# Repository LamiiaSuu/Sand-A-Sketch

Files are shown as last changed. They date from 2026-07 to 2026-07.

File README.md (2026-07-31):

# Sand A Sketch

Sand A Sketch - Hero Shot

The **Sand A Sketch** is a group project created for the university course Prototyping Interactive Objects (Summer 2026) at Hochschule RheinMain – University of Applied Sciences and Arts, Wiesbaden.

It is an **interactive drawing device** inspired by both the classic **Etch A Sketch** toy and **Kinetic Sand tables**. Instead of using a stylus or display, you can use a joystick to guide a small magnetic ball is moved on a plate filled with fine sand. As the magnet moves, it drags the ball through the sand, creating temporary drawings.

The movement is generated by a custom-built, mostly 3d-printed, [CoreXY mechanism](https://corexy.com/). It is powered by two stepper motors controlled by an Arduino. The joystick allows intuitive two-dimensional control while a potentiometer adjusts the drawing speed.

If you want to build your own Sand A Sketch you can! Just follow the instructions below.

Below you will find the:

- [materials](#materials-bom)
- [equipement](#equipment),
- [.stl-Files](#fabrication-files), 
- [code](#code)
- [Step-by-Step instructions](#step-by-step-instructions)

you need to build your own Sand A Sketch.

### Demo Videos

Drawing a...
- [bag](https://github.com/LamiiaSuu/Sand-A-Sketch/blob/6cb06aaf5f8eaca17e64170e79de1ecc5a618b9c/Footage/Showcase%20Videos/Bag.mp4)
- [heart](https://github.com/LamiiaSuu/Sand-A-Sketch/blob/6cb06aaf5f8eaca17e64170e79de1ecc5a618b9c/Footage/Showcase%20Videos/Heart.mp4)
- [house](https://github.com/LamiiaSuu/Sand-A-Sketch/blob/6cb06aaf5f8eaca17e64170e79de1ecc5a618b9c/Footage/Showcase%20Videos/House.mp4)

## MATERIALS (BOM)
- 1x [Arduino Nano](https://store.arduino.cc/products/arduino-nano)
- 1x Arduino Nano Power Cable
- 1x Breadboard
- Jumper Cables
- 2x 28BYJ-48 – 5V Stepper Motors
- 1x Joystick
- 1x Potentiometer
- 1x Cube Neodymium Magnet - 8 x 8 x 8 mm 
- 1x Magnetic ball - 8 mm
- 1x [6mm timing belt & pieces](https://amzn.eu/d/0blO36EH)
- 2x metal rods - 3 mm x 150 mm
- 2x metal rods - 3 mm x 200 mm
- fine mechanics oil

## EQUIPMENT

**Equipment**
- 3d printer

**Tools**
- cutter knife
- cutting mat
- scissors
- superglue

**Materials**
- Acrylic glass/Plexiglass
- Thick cardboard
- Fine sand/Quartz sand
- PLA filament

**Software**
- [Arduino IDE](https://docs.arduino.cc/software/ide/)
- [CheapStepper Library (v.0.2.1) by Tyler Henry](https://docs.arduino.cc/libraries/cheapstepper/)

## FABRICATION FILES

### Base Enclosure & Sand-Top
- 1x [SandTop.stl](stl/Base%20Enclosure%20%26%20SandTop/SandTop.stl) 
- 1x [Base Plate.stl](stl/Base%20Enclosure%20%26%20SandTop/Base%20Plate.stl) 
- 2x [Enclosure Corner Holder (Motor).stl](stl/Base%20Enclosure%20%26%20SandTop/Enclosure%20Corner%20Holder%20(Motor).stl) 
- 2x [Enclosure Corner Holder (No Motor).stl](stl/Base%20Enclosure%20%26%20SandTop/Enclosure%20Corner%20Holder%20(No%20Motor).stl) 
- *(Optional)* 5× [Cable Channel.stl](stl/Base%20Enclosure%20%26%20SandTop/Cable%20Channel.stl) 

### Controls 
- 1x [Controller Holder Clip.stl](stl/Controls/Controller%20Holder%20Clip.stl) 
- 1x [Upper Controller Part.stl](stl/Controls/Upper%20Controller%20Part.stl) 
- 1x [Lower Controller Part (Base).stl](stl/Controls/Lower%20Controller%20Part%20(Base).stl) 

### CoreXY 
- 1x [SandASketch_Magnet_Holder_Bottom.stl](stl/CoreXY/Individual/SandASketch_Magnet_Holder_Bottom.stl) 
- 1x [SandASketch_Magnet_Holder_Top.stl](stl/CoreXY/Individual/SandASketch_Magnet_Holder_Top.stl) 
- 2x [SandASketch_Motor_Corner.stl](stl/CoreXY/Individual/SandASketch_Motor_Corner.stl) 
- 2x [SandASketch_No_Motor_Corner.stl](stl/CoreXY/Individual/SandASketch_No_Motor_Corner.stl) 
- 2x [SandASketch_No_Motor_Corner_Bar.stl](stl/CoreXY/Individual/SandASketch_No_Motor_Corner_Bar.stl) 
- 2x [SandASketch_Side_Bar_150mm.stl](stl/CoreXY/Individual/SandASketch_Side_Bar_150mm.stl) 
- 2x [SandASketch_Side_Bar_159mm.stl](stl/CoreXY/Individual/SandASketch_Side_Bar_159mm.stl) 
- 2x [SandASketch_Side_Slider.stl](stl/CoreXY/Individual/SandASketch_Side_Slider.stl)
- 2x [SandASketch_Spool.stl](stl/CoreXY/Individual/SandASketch_Spool.stl)
- 4x [SandASketch_Spacer.stl](stl/CoreXY/Individual/SandASketch_Spacer.stl)

## CODE

You can download the code here:
[Sand A Sketch Code](https://github.com/LamiiaSuu/Sand-A-Sketch/blob/7b3ca9e36b72d740b66ece84b7ee0ffa8d913c48/Code/SandASketch.ino)

## STEP BY STEP INSTRUCTIONS

### Step 1: 3D Printing

1. Download all STL files from the [Fabriction Files](#fabrication-files) section 
2. Print all parts in the indicated quantities

**Recommended printer settings:**
- material: PLA
- layer height: 0.2 mm
- infill: 
	- 100% for [SandASketch_No_Motor_Corner_Bar.stl](stl/CoreXY/Individual/SandASketch_No_Motor_Corner_Bar.stl) 
	- 15% for all other parts

**Supports:** 
- **Required:** 
	- SandASketch_Spool.stl
	- SandASketch_Spacer.stl
- **All other parts** were printed successfully without supports on our printer. Depending on your printer and print settings, you may still want to enable supports for overhangs if necessary.

### Step 2: Assembling the CoreXY System

#### 2.1 Assembling the no-motor corners

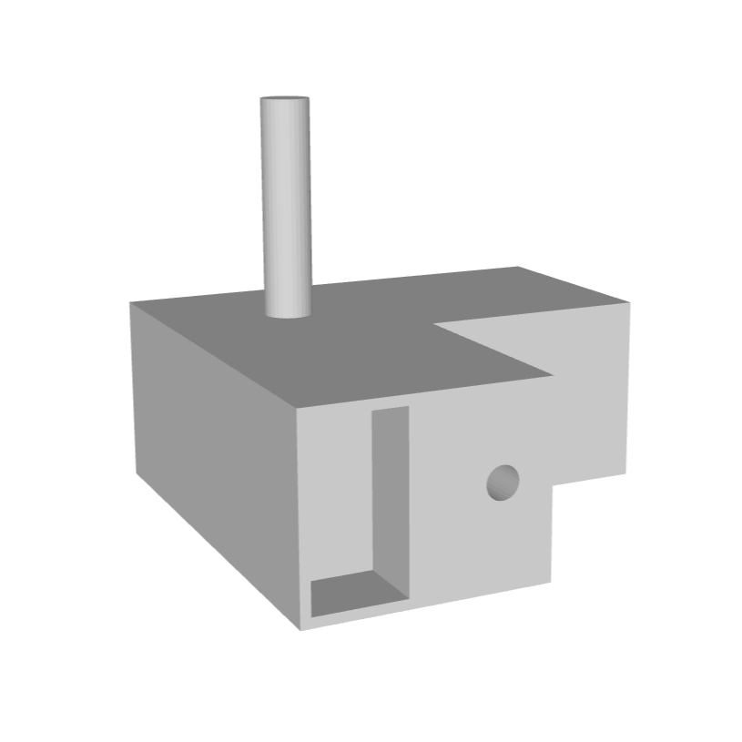
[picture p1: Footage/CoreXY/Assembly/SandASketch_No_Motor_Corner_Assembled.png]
Fully assembled No-Motor Corner

Fully assembled No-Motor Corner

You will need:
- 2x [SandASketch_No_Motor_Corner.stl](stl/CoreXY/Individual/SandASketch_No_Motor_Corner.stl) 
- 2x [SandASketch_No_Motor_Corner_Bar.stl](stl/CoreXY/Individual/SandASketch_No_Motor_Corner_Bar.stl) 
- superglue

1. Put a drop of **superglue** into the holes of the **No-Motor Corner** and insert the **bars** as deep as possible.
2. Wipe any excess glue and set aside to dry for a moment.

------

[Sand-A-Sketch - CoreXY Assembly Video](https://github.com/LamiiaSuu/Sand-A-Sketch/blob/593e7d0ba17ddbd5ef25c9bec1d4cd940d22d459/Footage/Assembly%20Videos/CoreXY%20Assembly.mp4)  
This video demonstrates the complete CoreXY assembly process. The written instructions below correspond to the same assembly.

-----

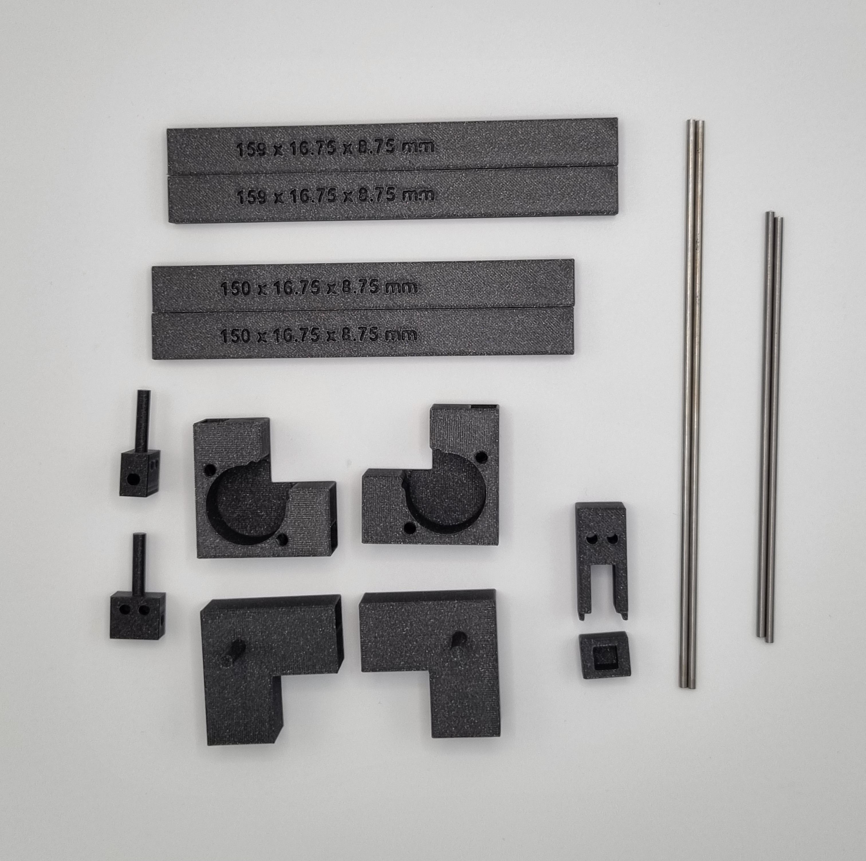
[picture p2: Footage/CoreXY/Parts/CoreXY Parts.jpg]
CoreXY Parts

CoreXY Parts

#### 2.2 Assemble both CoreXY sides
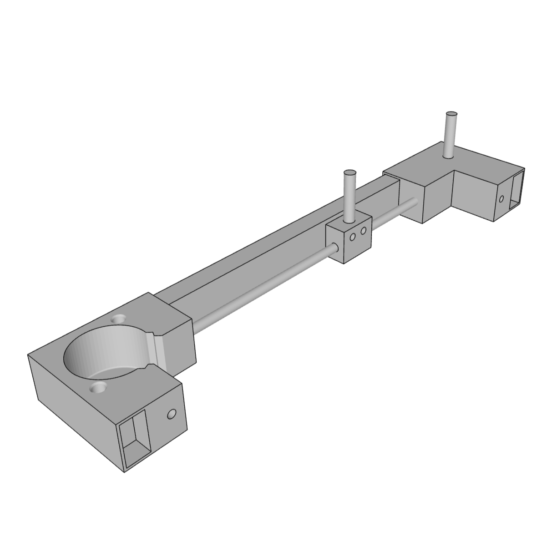
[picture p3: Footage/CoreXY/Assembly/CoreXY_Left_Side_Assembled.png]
Left CoreXY side assembled
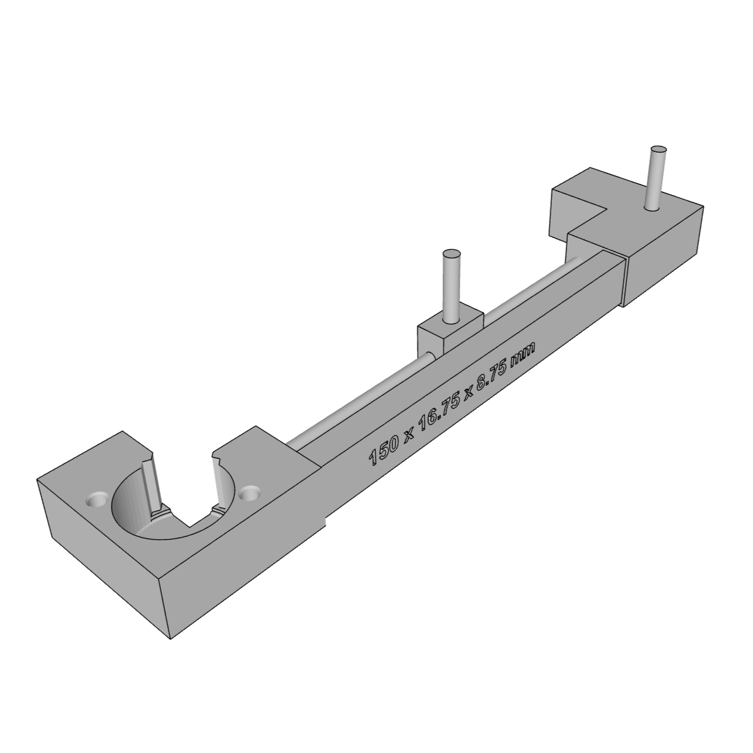
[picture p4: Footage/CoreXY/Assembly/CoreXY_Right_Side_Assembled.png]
Right CoreXY side assembled
|  |  |
|--|--|
| Left CoreXY side | Right CoreXY side |

You will need **for each side**:
- 1x [SandASketch_Motor_Corner.stl](stl/CoreXY/Individual/SandASketch_Motor_Corner.stl) 
- 1x [SandASketch_Side_Bar_150mm.stl](stl/CoreXY/Individual/SandASketch_Side_Bar_150mm.stl) 
- 1x [SandASketch_Side_Slider.stl](stl/CoreXY/Individual/SandASketch_Side_Slider.stl)
- 1x assembled No_Motor_Corner + Bar
- 1x metal rod - 3 mm x 150 mm

First, assemble the **left CoreXY side** by referencing the **left image** above.

1. Orient the **Motor Corner** as shown.
2. Insert the **Side Bar** and **metal rod** into the upper arm of the corner.
3. Slide the **Side Slider** onto the metal rod. Make sure the holes on the side point towards the middle, away from the bar.
4. Orient the **No-Motor Corner** as shown.
5. Insert the free ends of the **Side Bar** and the **metal rod** into the **No-Motor Corner**.

Now **repeat** these steps to assemble the **right CoreXY side** by referencing the **right image.**

#### 2.3 Connect both CoreXY sides
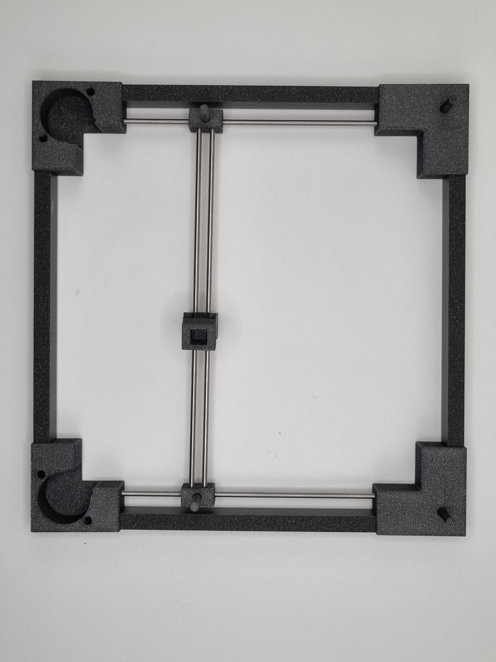
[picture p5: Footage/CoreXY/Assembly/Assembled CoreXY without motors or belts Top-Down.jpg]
Assembled CoreXY - top down
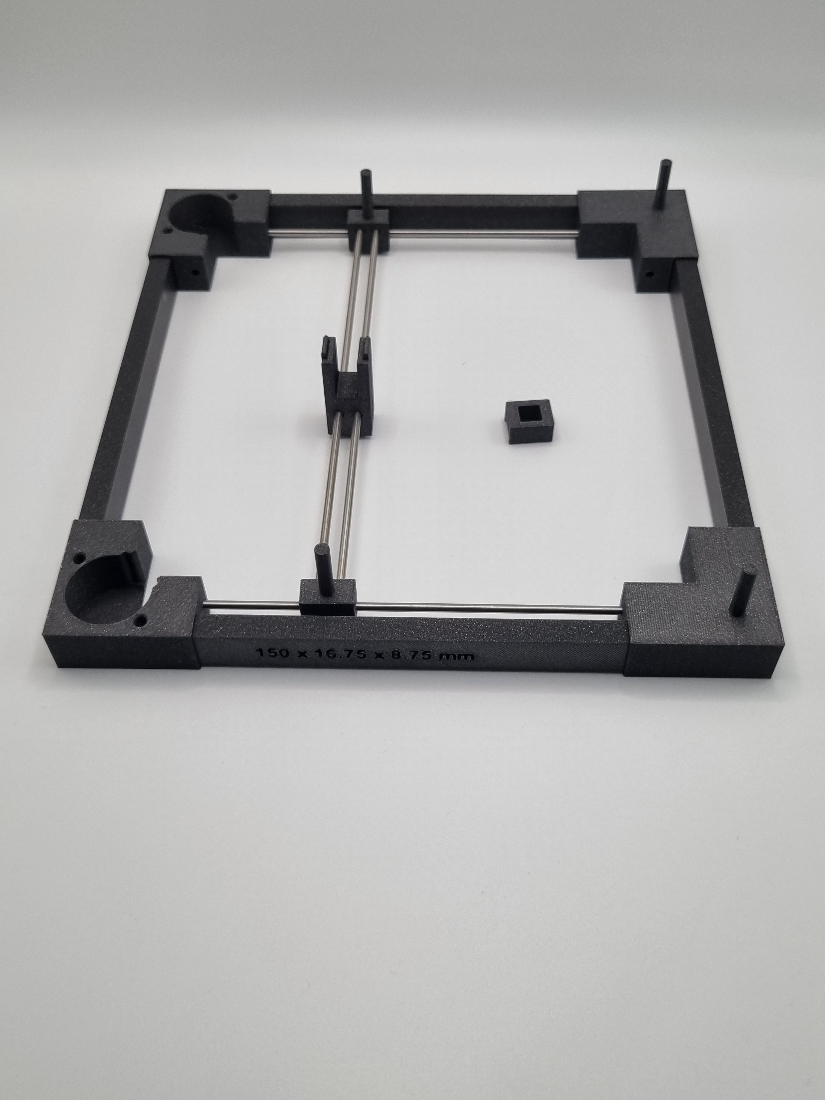
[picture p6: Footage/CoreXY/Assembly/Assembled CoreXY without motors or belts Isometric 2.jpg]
Assembled CoreXY - Isometric
|  |  |
|--|--|
| Assembled CoreXY - top down | Assembled CoreXY - Isometric |

You will need:
- 1x fully assembled left CoreXY side
- 1x fully assembled right CoreXY side
- 2x [SandASketch_Side_Bar_159mm.stl](stl/CoreXY/Individual/SandASketch_Side_Bar_159mm.stl) 
- 1x [SandASketch_Magnet_Holder_Bottom.stl](stl/CoreXY/Individual/SandASketch_Magnet_Holder_Bottom.stl) 
- 2x metal rods - 3 mm x 200 mm

1. Take the **left CoreXY side**.
2. Insert the **Side Bars** into the holes of its **Motor Corner** and **No-Motor Corner**.
3. Insert both **metal rods** into the holes of the **Side Slider**.
4. Slide the **Magnet Holder Bottom** onto both metal rods.
5. Take the **right CoreXY side** and insert the free ends of the **Side Bars** and **metal rods** into it. 

**Tip**
Step 5 can be a bit tricky to do alone. If possible, ask a second person to help you.

**Important** 
Do **not** attach the **Magnet Holder Top** onto the Magnet Holder bottom yet.

Your CoreXY should now look as above. 

#### 2.4 Inserting the Motors

You will need:
- 1x assembled CoreXY
- 2x 28BYJ-48 – 5V Stepper Motors

1. Insert a stepper motor into each **Motor Corner**.
2. Press each motor firmly into place until it is fully seated.

**Note**
The fit is intentionally tight to keep the motors in place.

#### 2.5 Placing the Timing Belt Pulleys

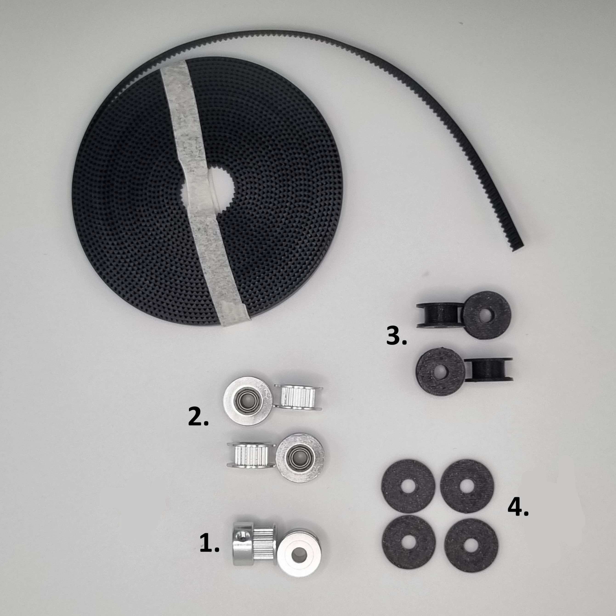
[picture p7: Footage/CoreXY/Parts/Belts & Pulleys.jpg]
Timing Belt, Spools and Spacers

Timing Belt and components.
Parts are labelled **1–4** and referenced in the steps below.

You will need:
- 1x assembled CoreXY with motors inserted
- 2x [SandASketch_Spool.stl](stl/CoreXY/Individual/SandASketch_Spool.stl)
- 4x [SandASketch_Spacer.stl](stl/CoreXY/Individual/SandASketch_Spacer.stl)
- 1x [6mm timing belt & pieces](https://amzn.eu/d/0blO36EH)

1. Take the two pulleys labelled **1** in the image above. Press one onto each stepper motor shaft and tighten the set screws. Your assembly should now look like the image below.
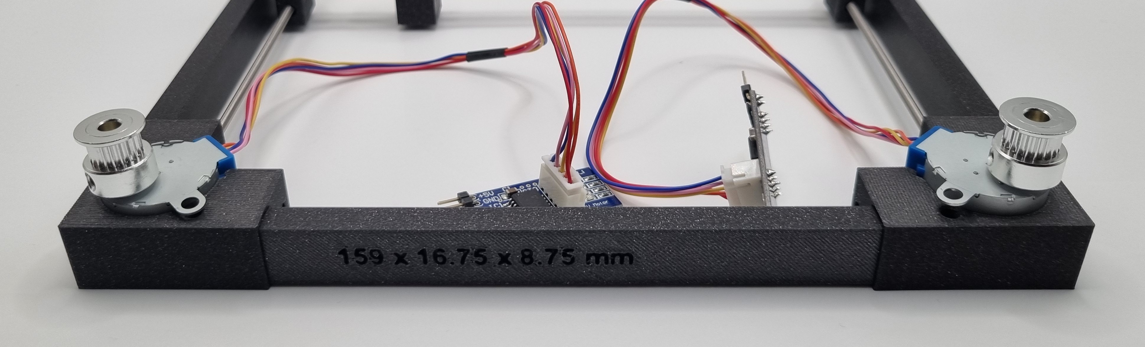
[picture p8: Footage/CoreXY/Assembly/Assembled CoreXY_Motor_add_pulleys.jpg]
Motors with pulleys added

2. Take the two pulleys labelled **2** and place one onto each **No-Motor Corner**.
3. Place one **Spacer** (labelled **3**) on top of each pulley, then place the remaining two pulleys labelled **2** on top.
4. Place one printed **Spool** (labelled **4**) onto each **Side Slider**.
5. Place one **Spacer** on top of each printed spool, then place the remaining two printed spools on top.

Your CoreXY should now look like this:
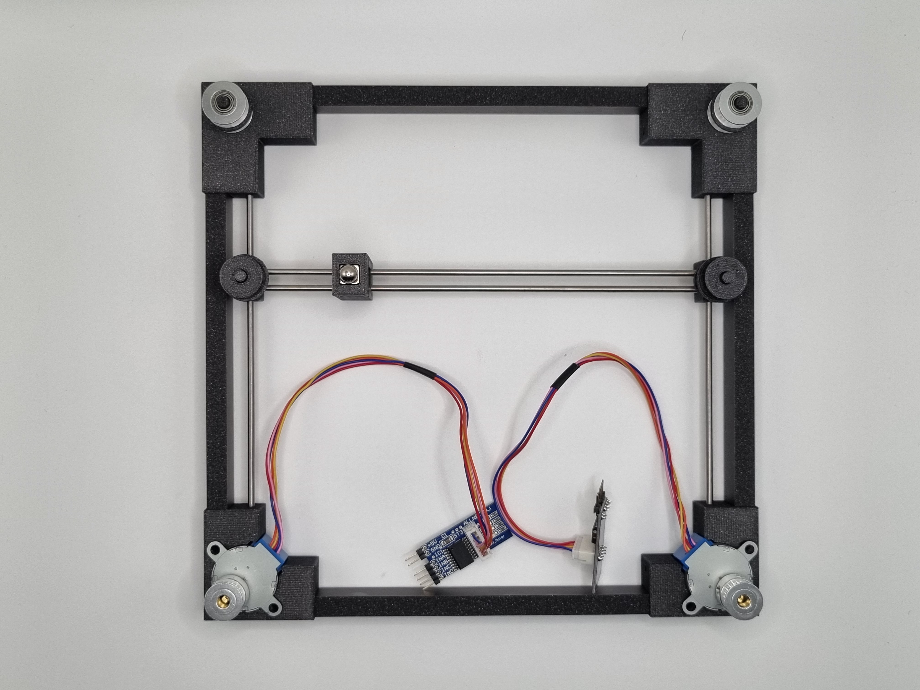
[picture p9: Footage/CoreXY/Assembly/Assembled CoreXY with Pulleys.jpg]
CoreXY with Pulleys
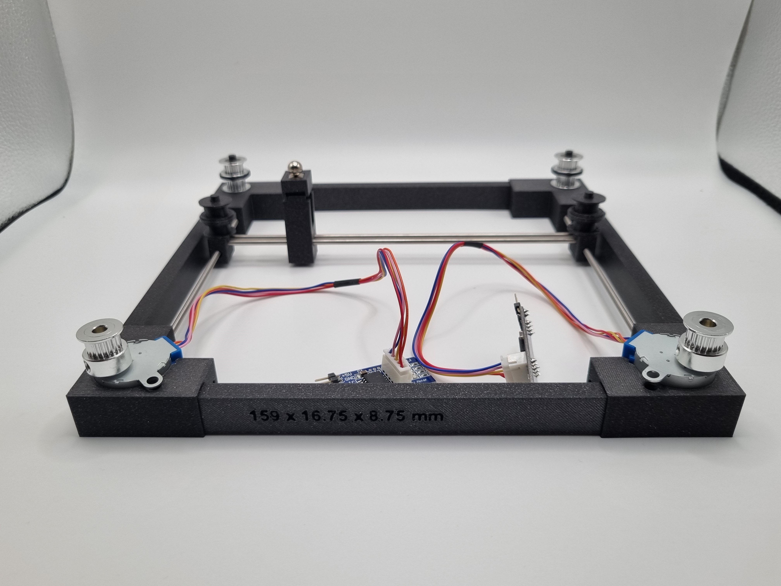
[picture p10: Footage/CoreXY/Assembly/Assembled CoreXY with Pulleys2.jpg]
CoreXY with Pulleys 2
|  |  |
|--|--|
CoreXY with pulleys *(magnet shown for illustration only)*

#### 2.6 Installing the Timing Belt

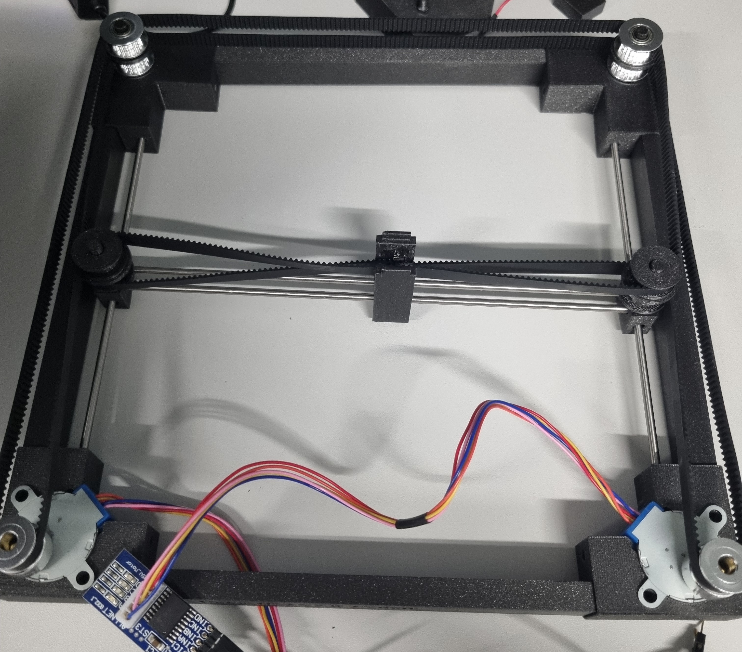
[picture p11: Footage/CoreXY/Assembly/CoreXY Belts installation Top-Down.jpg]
Installed Timing Belt

Installed Timing Belt

You will need:
- 1x assembled CoreXY with motors & pulleys
- 1x [6mm timing belt & pieces](https://amzn.eu/d/0blO36EH)
- scissors
- superglue

Refernce:  
[Manual CoreXY Mechanism by DrRonny on Thingiverse](https://www.thingiverse.com/thing:4167459)  

1. Place the CoreXY in front of you with the Motor Corners closest to you.

**Belt 1:**

2. Take the end of the **Timing Belt** and carefully glue it towards the top of the inside closest to you of the **Magnet Holder Bottom**. The teeth of the belt should be showing away from you/the motors.
3. Route the belt around the pulleys exactly as shown in the refernce. 
4. Cut the belt with 2-3 cm of ease.

**Belt 2:**

5. Take the end **Timing Belt** and carefully glue it towards the bottom of the inside furthest away from you of the **Magnet Holder Bottom**. The teeth of the belt should be in the same direction as **Belt 1**.
6. Route the belt around the pulleys exactly as shown in the refernce. 
7. Cut the belt with 2-3 cm of ease.

**Tensioning:**

8. Pull one belts taut, but not too tight. The Side Slider should **not** be pulled towards the inside of the CoreXY.
9. Use superglue to glue it right beside its other end.
10. Repeat for the other belt .
11. Wait for the glue to fully dry.

#### 2.7 Checking tension

- 1x assembled CoreXY with motors, pulleys & timing belt
- fine mechanics oil
- scissors

1. Aplly some fine mechanics oil to all metal rods
2. Test if the **Side Sliders** move smoothly and the two **metal rods** holding the  **Magnet Holder Bottom** are straight. 
3. Test if the **Magnet Holder Bottom** slides smoothly.
4. Cut the excess Timing Belt off.

**Important**
If the metal rods are not straight the CoreXY will **not** work correctly.
In this case you will likely need to **adjust the tension of the Timing Belt** again.

#### 2.8 Adding the magnet

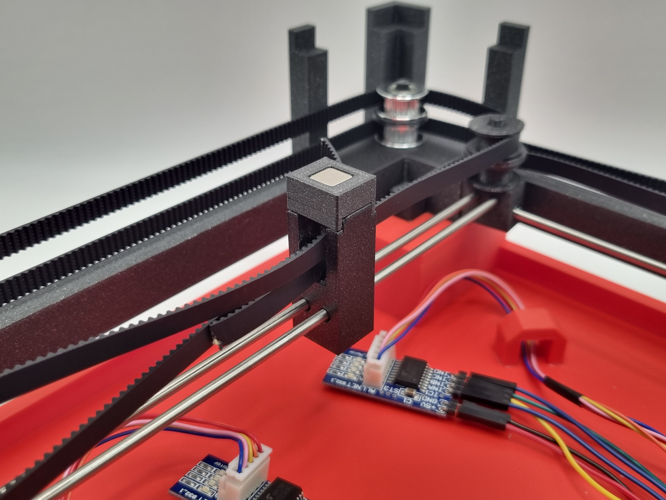
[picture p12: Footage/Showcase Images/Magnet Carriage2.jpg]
Magnet Holder


You will need:
- 1x assembled CoreXY
- 1x [SandASketch_Magnet_Holder_Top.stl](stl/CoreXY/Individual/SandASketch_Magnet_Holder_Top.stl) 
- 1x Cube Neodymium Magnet - 8 x 8 x 8 mm 

1. Place the **magnet** into the **Magnet Holder Top**.
2. Press the **Magnet Holder Top** onto the **Magnet Holder Bottom** until it fits snug.

You have finished assembling the CoreXY!

### Step 3: Assembling the Base Enclosure

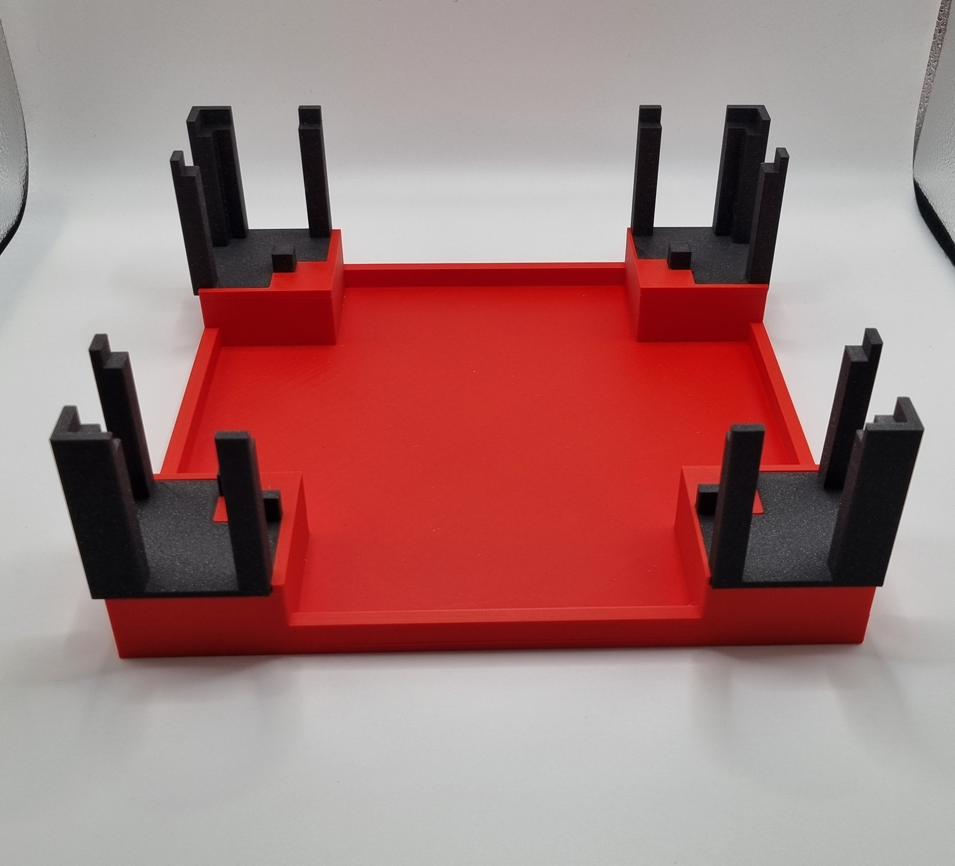
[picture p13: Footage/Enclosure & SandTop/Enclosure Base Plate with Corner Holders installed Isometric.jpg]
Base Enclosure with Corner Holders

Base Enclosure with Corner Holders

You will need:
- 1x assembled CoreXY
- 1x [Base Plate.stl](stl/Base%20Enclosure%20%26%20SandTop/Base%20Plate.stl) 
- 2x [Enclosure Corner Holder (Motor).stl](stl/Base%20Enclosure%20%26%20SandTop/Enclosure%20Corner%20Holder%20(Motor).stl) 
- 2x [Enclosure Corner Holder (No Motor).stl](stl/Base%20Enclosure%20%26%20SandTop/Enclosure%20Corner%20Holder%20(No%20Motor).stl) 
- superglue

1. Take the **Motor Corner Holders** and click them onto the fitting corners of the **Base Plate** as shown.
2. Apply some superglue to the other two corners of the **Base Plate**
3. Place the **No-Motor Corner Holders** ontop of the glue and press down. Wipe any excess glue.
4. Before drying, put the CoreXY into the holders. This makes sure that all Corner Holder sit straight.

**Important**
Make sure not to glue the CoreXY into place, this way it can still be taken out later.

### Step 4: Assembling the Controls

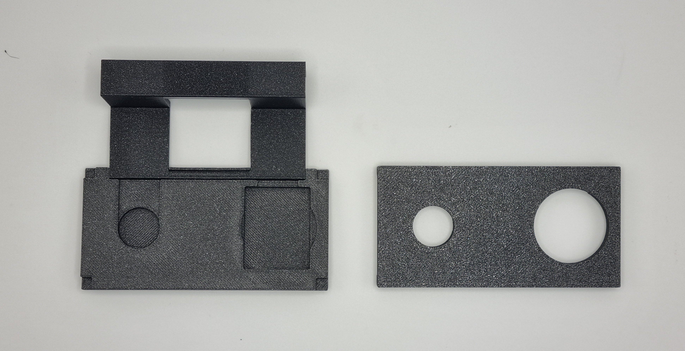
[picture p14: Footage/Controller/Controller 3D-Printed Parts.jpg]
Controller parts
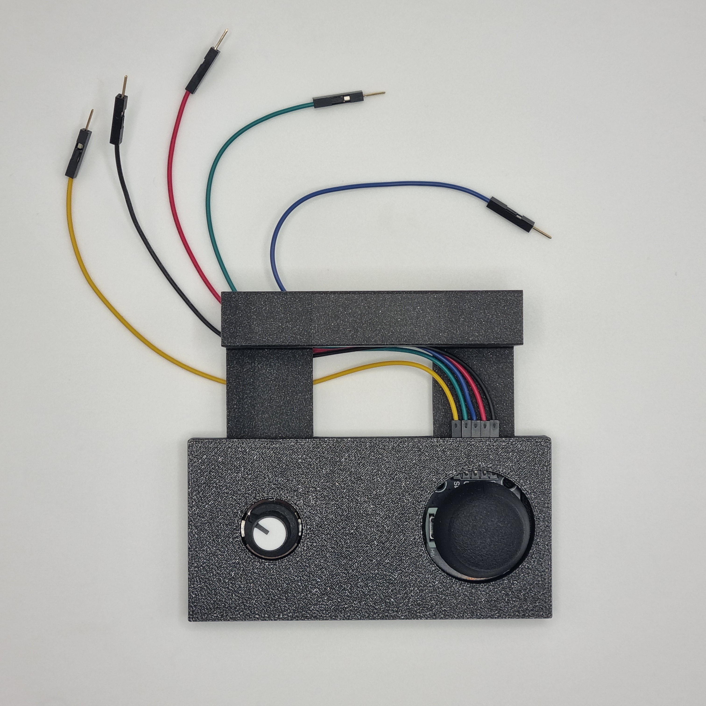
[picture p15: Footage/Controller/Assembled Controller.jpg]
Assembled controller
|  |  |
|--|--|
| Controller Parts | Assembled controller |

You will need:
- 1x assembled CoreXY with enclosure
- 1x [Controller Holder Clip.stl](stl/Controls/Controller%20Holder%20Clip.stl) 
- 1x [Upper Controller Part.stl](stl/Controls/Upper%20Controller%20Part.stl) 
- 1x [Lower Controller Part (Base).stl](stl/Controls/Lower%20Controller%20Part%20(Base).stl) 
- 1x Joystick
- 1x Potentiometer
- Jumper Cables

1. Install the **Holder Clip** into the **Lower Controller Part**.
2. Put **jumper cables** onto the **Joystick** and **Potentiometer**.
3. Place the **Potentiometer** into the left indentation and the **Joystick** into the right indentation of the **Lower Controller Part** with the jumper cables going towards the Holder Clip. Like this:
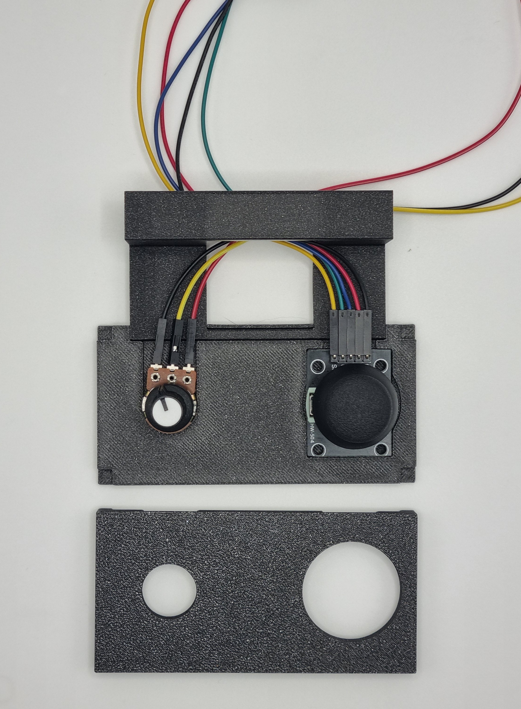
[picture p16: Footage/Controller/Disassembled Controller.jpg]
Placement in Controller


4. Pull the free end of the **jumper cables** through the hole of the **Holder Clip**.
5. Press the **Upper Controller Part** onto the **Lower Controller Part** until it clicks into place.
6. Hang the **Holder Clip** onto the **Side Bar** of the CoreXY between both motors.

### Step 5: Assembling the Sand-Top

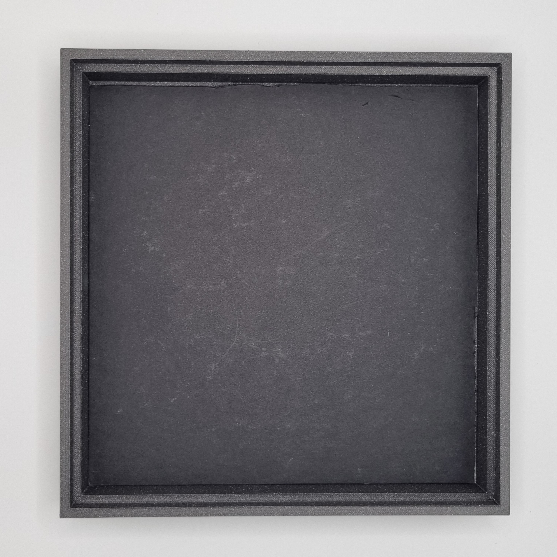
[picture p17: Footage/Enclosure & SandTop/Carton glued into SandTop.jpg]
Sand-Top with cardboard

Sand-Top with cardboard

You will need:
- 1x [SandTop.stl](stl/Base%20Enclosure%20%26%20SandTop/SandTop.stl) 
- Thick cardboard
- Fine sand/Quartz sand
- cutter knife
- cutting mat
- super glue

1. Cut the **cardboard** to fit onto the lower inner edge of the **Sand-Top**.
2. Glue the **cardboard** onto the lower inner edge of the **Sand-Top** with **superglue**.
3. Wait until the glue has dried.
4. Fill the Sand-Top with **sand** until it reaches approximately half the diameter of the magnetic ball (roughly 4 mm).

Put this to the side for now.

### Step 6: Wiring

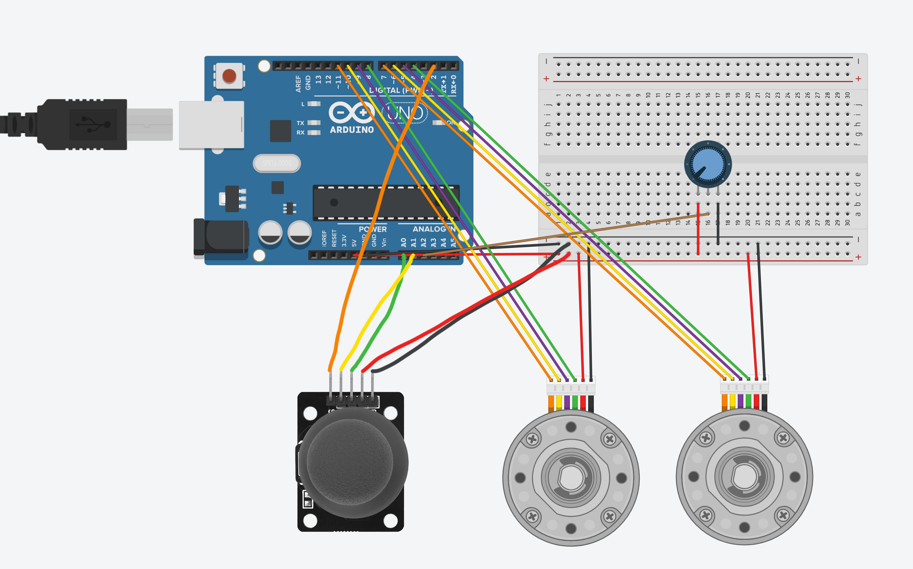
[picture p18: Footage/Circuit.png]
Wiring Diagram

Wiring Diagram

You will need:
- 1x assembled CoreXY with enclosure & controls
- 1x Arduino Nano
- 1x Arduino Nano Power Cable
- 1x Breadboard
- Jumper Cables
- *(Optional)* 5× [Cable Channel.stl](stl/Base%20Enclosure%20%26%20SandTop/Cable%20Channel.stl) 
- *(Optional)* superglue

1. Place your **Arduino Nano** on your **breadboard** and connect the **power cable**.
2. Place your **breadboard** into the **base** of the enclosure.
3. Use the **wiring diagramm** above to connect the **motors** and **controls** to the **Arduino Nano** on the breadboard.

*Optional*
You can use some **Cable Channels** to secure your **jumper cables**:

4. Arrange your **jumper cables**.
5. Place some **superglue** on the bottom of a **Cable Channel**.
6. Press the **Cable Channel** wherever you want to place it.

**Important**
Always double **check** your components **datasheets** when wiring. Accidentally swapping ground and volt can damage your components.

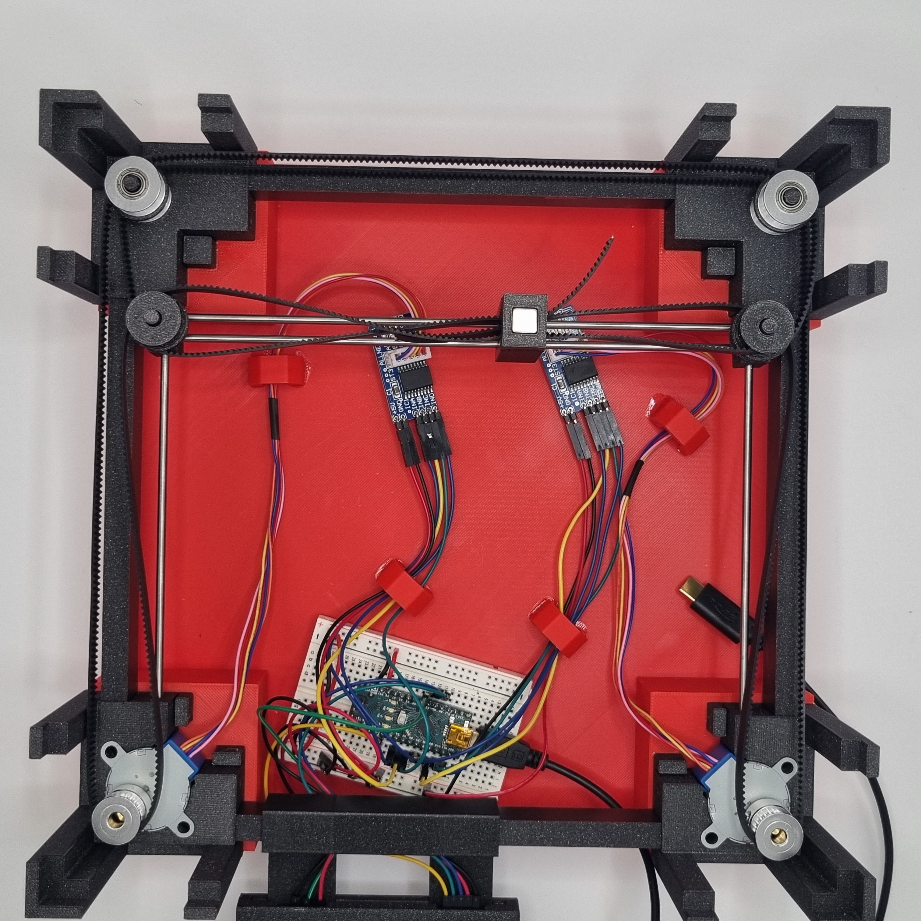
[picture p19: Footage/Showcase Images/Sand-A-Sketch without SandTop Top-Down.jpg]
Wiring - Middle
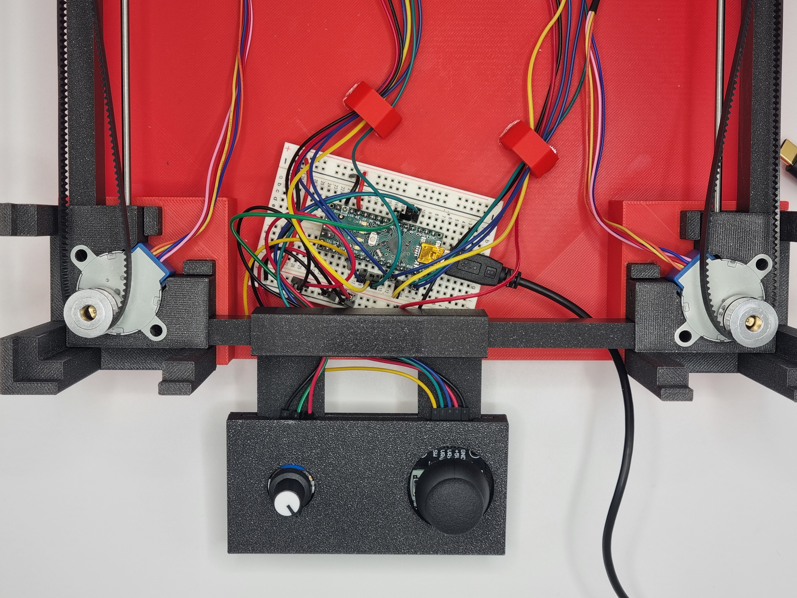
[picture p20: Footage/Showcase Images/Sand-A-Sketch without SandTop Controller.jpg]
Wiring - controller
|  |  |
|--|--|
Finished wiring with cable channels.

### Step 7: Code

You will need:
- a computer
- the [Arduino IDE](https://docs.arduino.cc/software/ide/)
- the [CheapStepper Library (v.0.2.1) by Tyler Henry](https://docs.arduino.cc/libraries/cheapstepper/)
- the [Code](#code) 

1. Install the **Arduino IDE**.
2. Install the **CheapStepper Library** (v.0.2.1) by Tyler Henry in the Arduino IDE.
3. Download the **code** and open it in the Arduino IDE
4. Connect the **Arduino Nano** to your computer
5. Select **Arduino Nano** as the board and the correct **port**
6. Upload the **code** onto the Arduino Nano

**Note**
If you have trouble uploading the code double check that you have selected the correct board and port.

### Step 8: Final Assembly

- 1x assembled CoreXY with Base Enclosure, Controls and finished wiring
- 1x Sand-Top
- Acrylic glass/Plexiglass
- cutter knife
- cutting mat
- 1x Magnetic ball - 8 mm

1. ***Carefully*** cut the **acrylic glass** so it fits onto the top inner edge of the **Sand-Top**.
2. Place your **Sand-Top** ontop of the **Corner Holders**. If it doesn't fit one way, turn it 90 degrees and try again.
3. Place the **magnetic ball** onto the sand, directly above the **Magnet Holder**.
5. Place the acrylic glass onto the top inner edge of the **Sand-Top**.

### Step 9: Have fun!

1. Draw your first temporary sand image!
2. Shake the **Sand A Sketch** carefully to erase image.
3. Repeat!

## LICENCE AND CREDITS

Attribution — ShareAlike CC BY-SA 

This interactive object and accompanying tutorial has been designed by Robert Bothfeld, Iris Henkel and Jaqueline Huth during the course Prototyping Interactive Objects (Summer 2026) at Hochschule RheinMain – University of Applied Sciences and Arts, Wiesbaden.

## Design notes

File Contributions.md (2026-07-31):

## Robert

- Project conception and design (We all contributed to this)
- Conceptualization, 3D modeling and 3D printing of all components except the CoreXY system (sand top, enclosure, cable channels, controller, etc.)
- Procurement of additional materials (fine sand and steel rods)
- Cutting and preparing the non-printed components for the sand top (cardboard and acrylic sheet)
- Video Editing
- Documentation
- Organizing & Reviewing Footage

## Iris
- Paper-Prototyp
- 3D Design und Druck (Spulen, Spacer und Stäbe)
- Konfiguration der Hardware und Code geschrieben
- Assemblen des Prototypen 
- Fotos für die Dokumentation 
- Plakaterstellung

## Jacky
- Project conception and design
- Conceptualization, 3D modeling and 3D printing of the CoreXY system
- Assembling the CoreXY & final protoyp
- Taking pictures & videos for the documentation
- Code cleanup
- Documentation

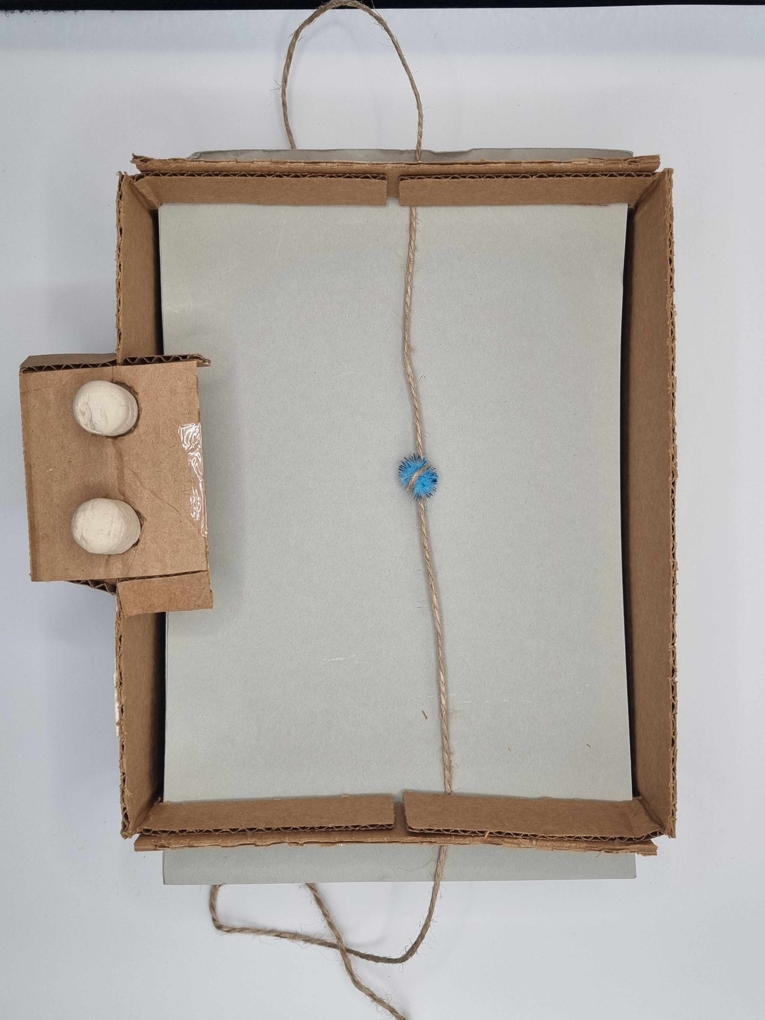
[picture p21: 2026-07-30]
Footage/Paper Prototype/Paper Prototype with blue ball bearing.jpg

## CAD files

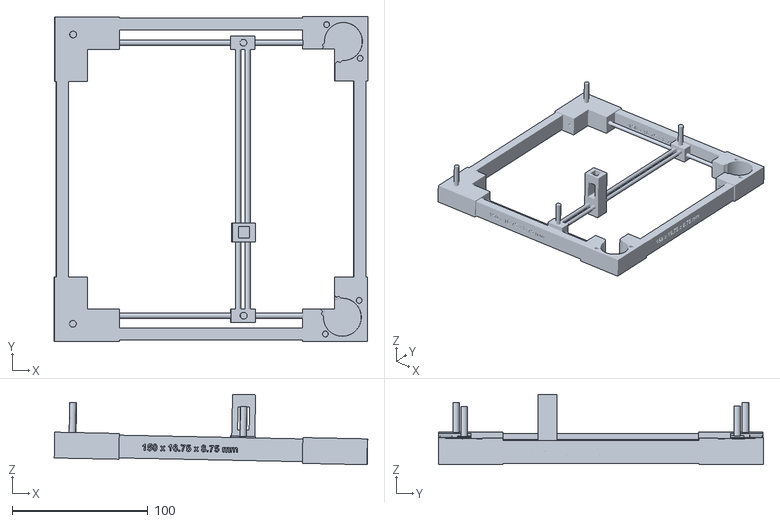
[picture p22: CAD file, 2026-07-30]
stl/CoreXY/Complete/SandASketch_CoreXY_Assembled.stl
230.6 x 239.0 x 51.8

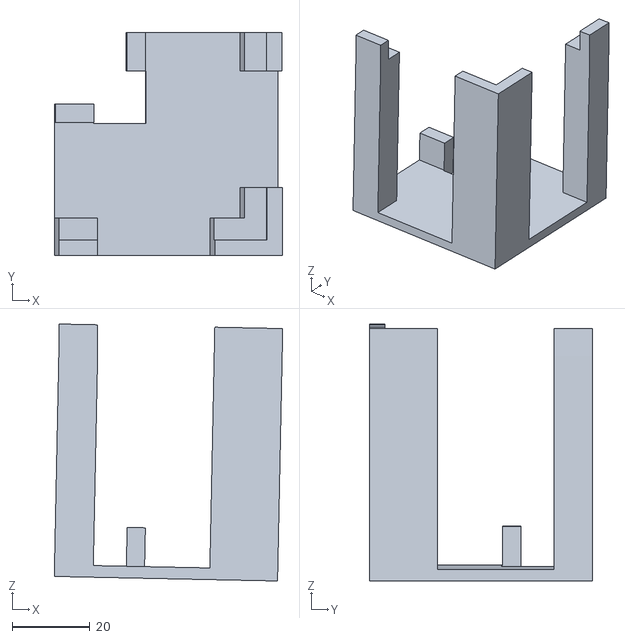
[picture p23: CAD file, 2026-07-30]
stl/Base Enclosure & SandTop/Enclosure Corner Holder (Motor).stl
58.8 x 57.5 x 66.2

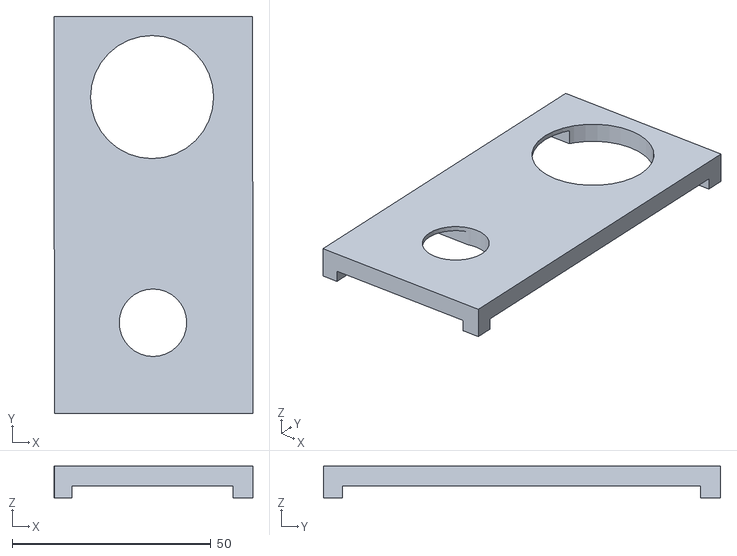
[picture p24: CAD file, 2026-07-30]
stl/Controls/Upper Controller Part.stl
50.0 x 100.0 x 8.00

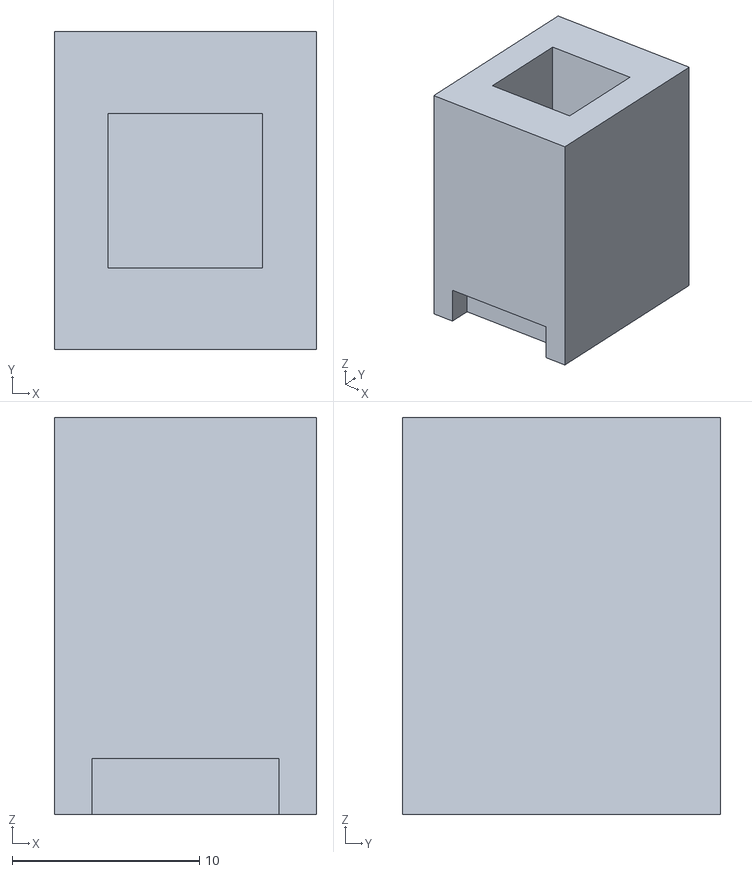
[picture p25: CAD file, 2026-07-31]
stl/CoreXY/Individual/SandASketch_Magnet_Holder_Top.stl
14.0 x 17.0 x 21.2

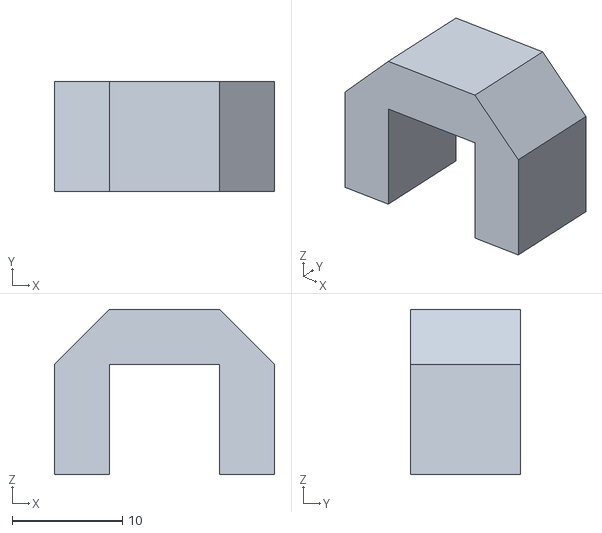
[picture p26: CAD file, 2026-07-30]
stl/Base Enclosure & SandTop/Cable Channel.stl
20.0 x 10.0 x 15.0

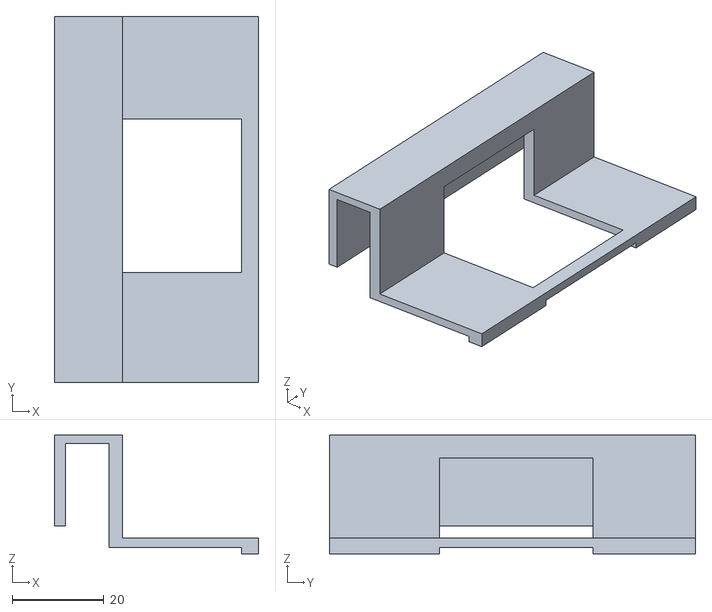
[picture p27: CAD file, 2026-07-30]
stl/Controls/Controller Holder Clip.stl
44.6 x 80.0 x 25.9

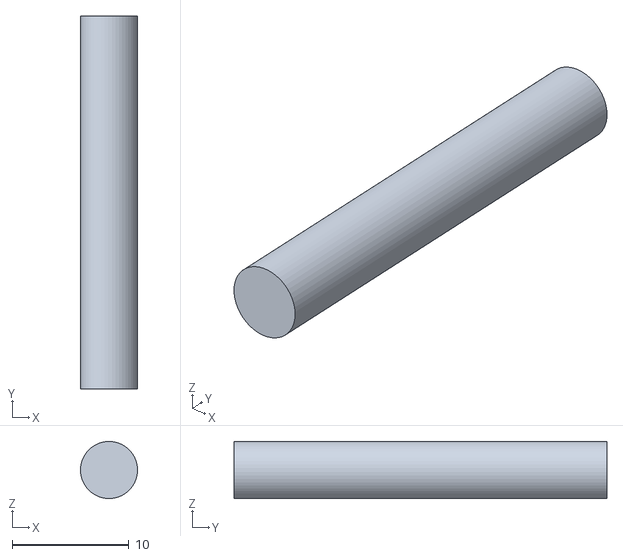
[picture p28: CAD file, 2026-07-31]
stl/CoreXY/Individual/SandASketch_No_Motor_Corner_Bar.stl
4.89 x 32.0 x 4.90

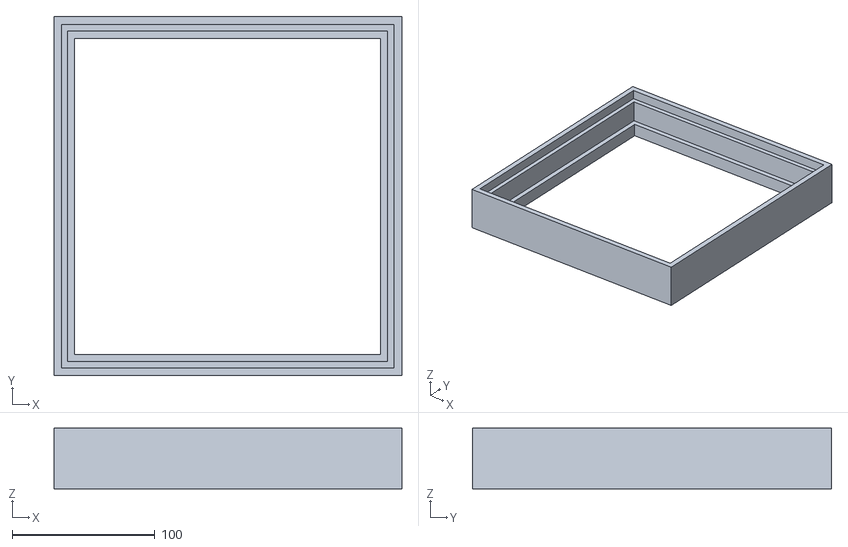
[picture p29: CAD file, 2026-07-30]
stl/Base Enclosure & SandTop/SandTop.stl
244.0 x 252.0 x 42.6

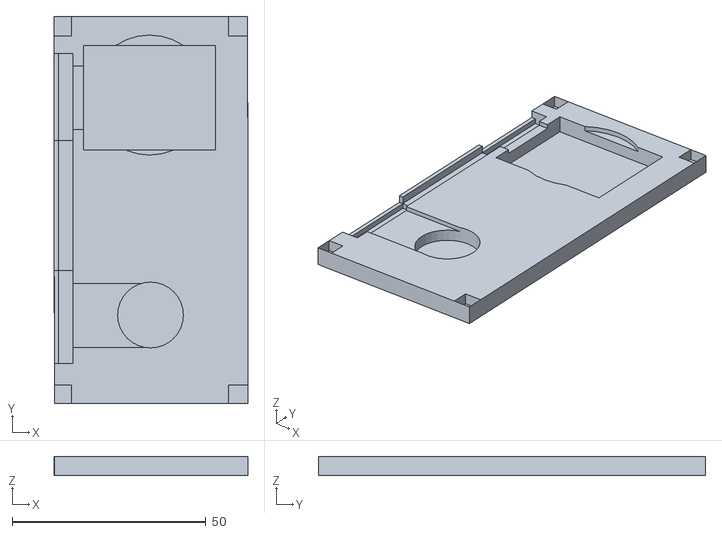
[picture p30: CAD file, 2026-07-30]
stl/Controls/Lower Controller Part (Base).stl
50.0 x 100.0 x 5.00

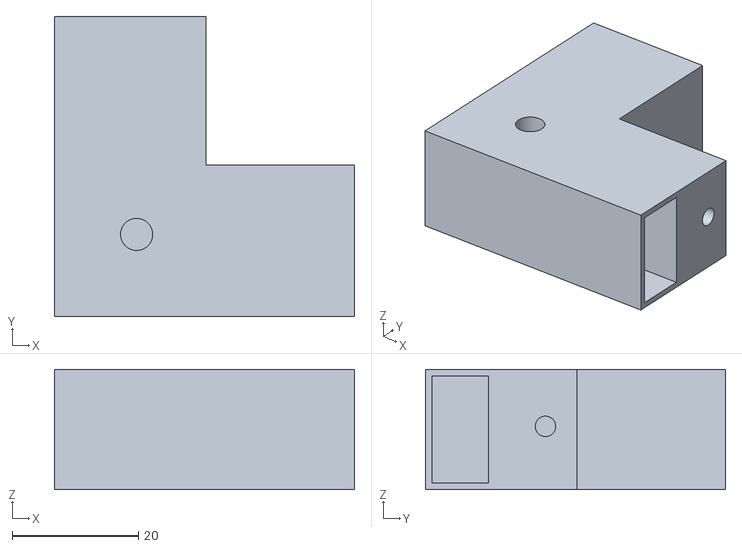
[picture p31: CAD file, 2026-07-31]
stl/CoreXY/Individual/SandASketch_No_Motor_Corner.stl
47.5 x 47.5 x 19.0

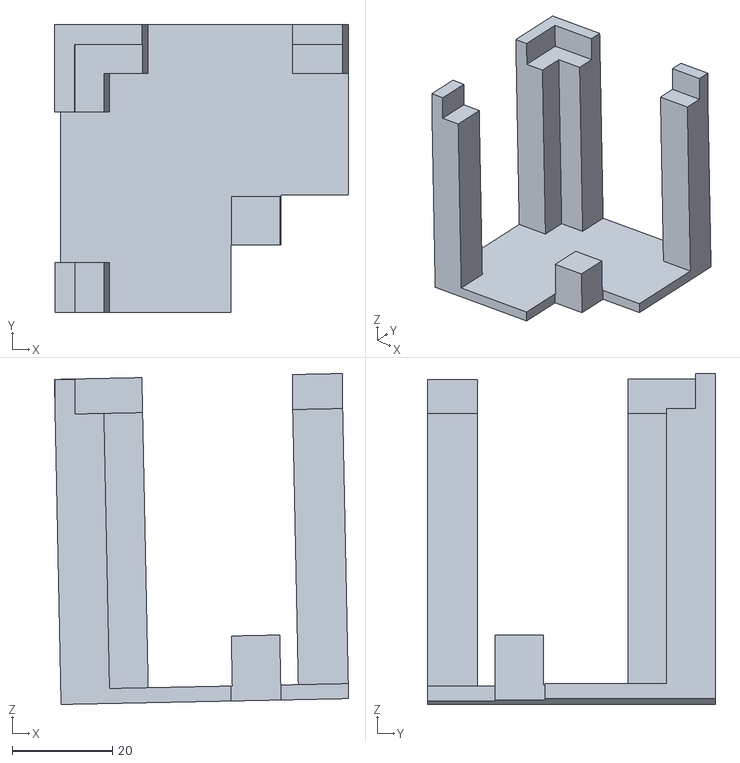
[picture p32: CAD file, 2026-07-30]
stl/Base Enclosure & SandTop/Enclosure Corner Holder (No Motor).stl
58.8 x 57.5 x 66.2

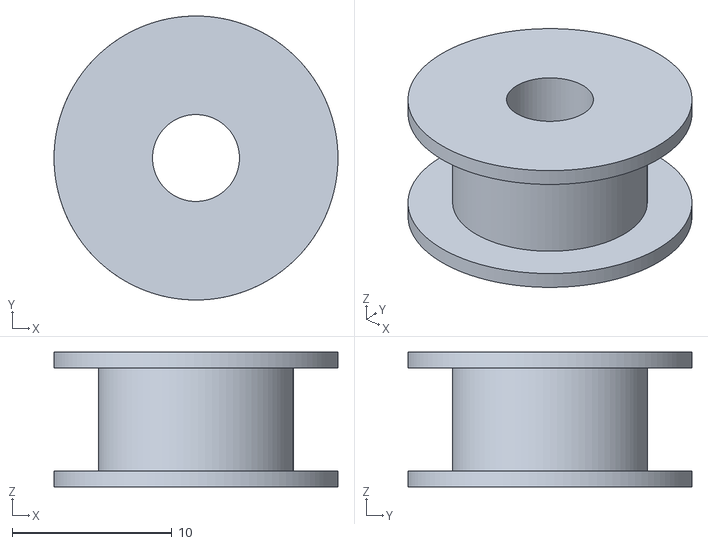
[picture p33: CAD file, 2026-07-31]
stl/CoreXY/Individual/SandASketch_Spool.stl
17.8 x 17.8 x 8.45

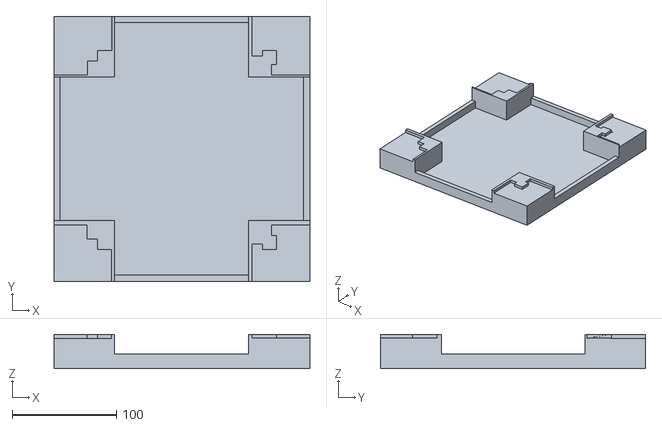
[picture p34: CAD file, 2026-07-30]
stl/Base Enclosure & SandTop/Base Plate.stl
246.0 x 254.9 x 32.9

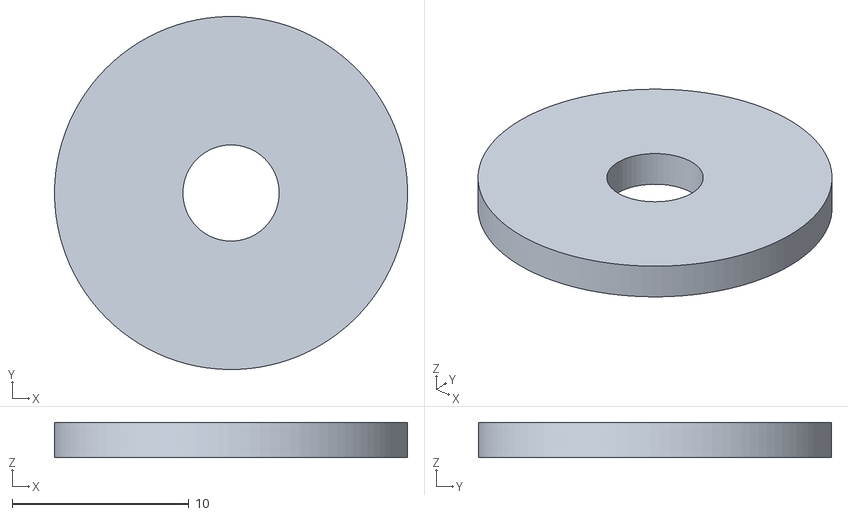
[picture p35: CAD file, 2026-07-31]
stl/CoreXY/Individual/SandASketch_Spacer.stl
20.0 x 20.0 x 2.00

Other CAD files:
stl/CoreXY/Individual/SandASketch_Side_Slider.stl
stl/CoreXY/Individual/SandASketch_Magnet_Holder_Bottom.stl
stl/CoreXY/Individual/SandASketch_Motor_Corner.stl
stl/CoreXY/Individual/SandASketch_Side_Bar_150mm.stl
stl/CoreXY/Individual/SandASketch_Side_Bar_159mm.stl

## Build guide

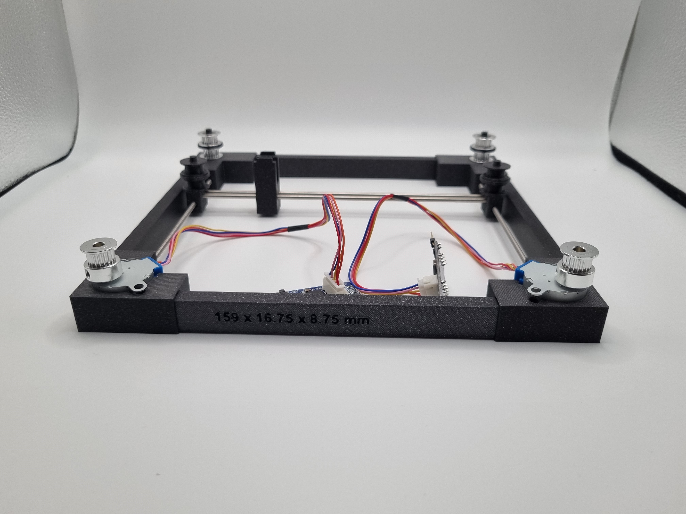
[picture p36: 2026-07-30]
Footage/CoreXY/Assembly/Assembled CoreXY.jpg

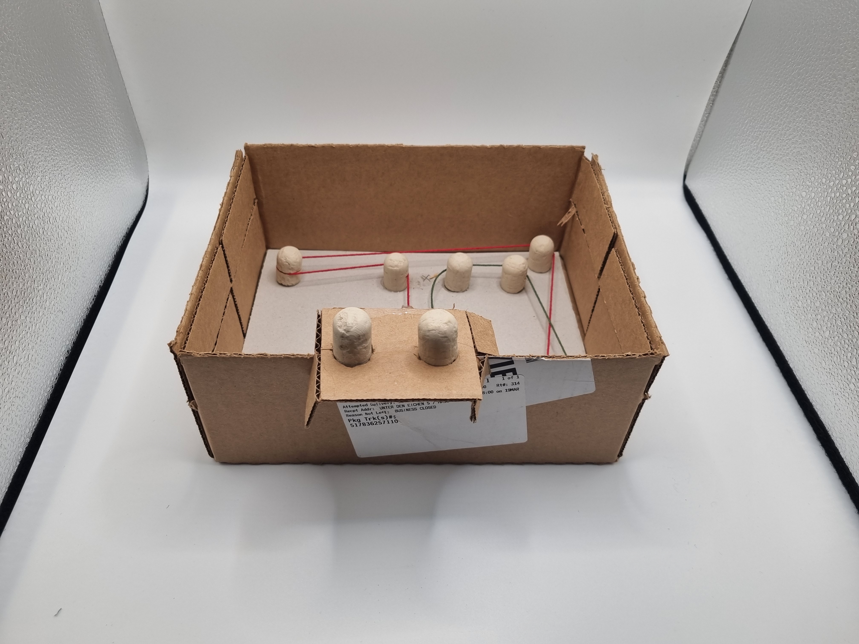
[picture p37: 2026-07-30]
Footage/Paper Prototype/Paper Prototype Assembled Side.jpg

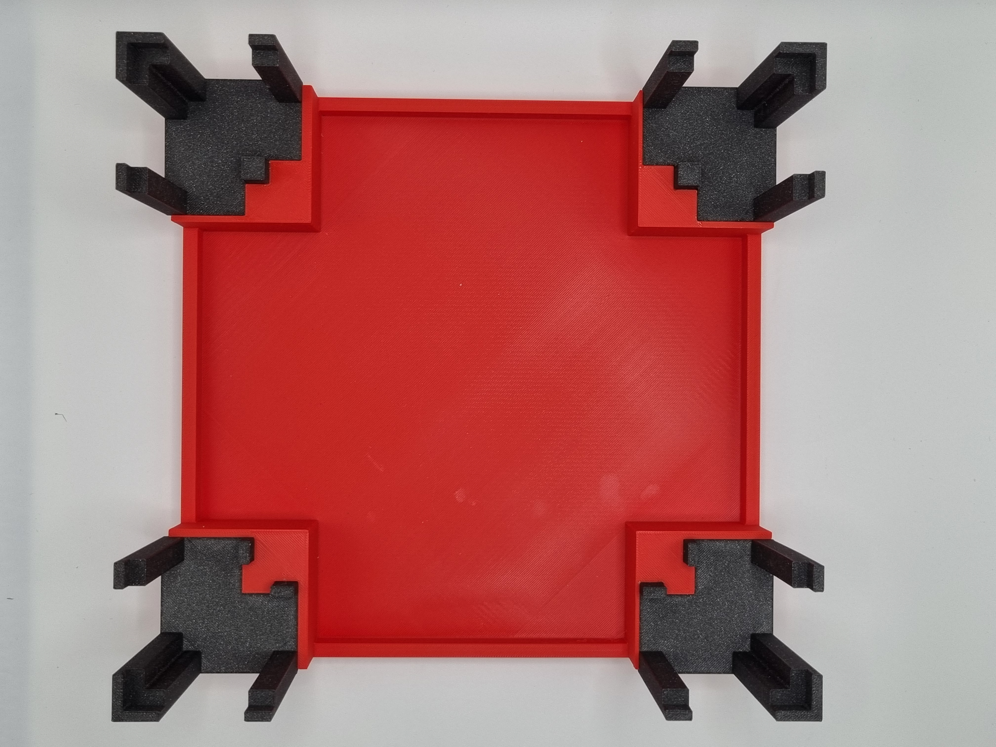
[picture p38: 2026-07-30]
Footage/Enclosure & SandTop/Enclosure Base Plate with Corner Holders installed.jpg

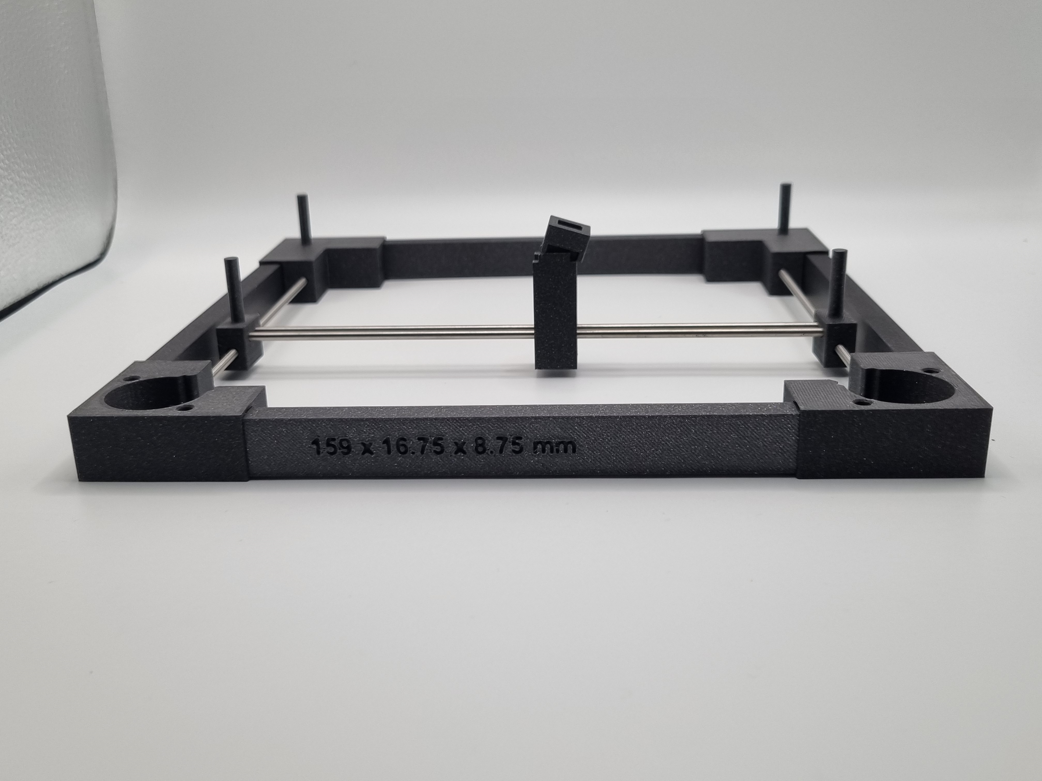
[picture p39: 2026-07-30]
Footage/CoreXY/Assembly/Assembled CoreXY without motors or belts.jpg

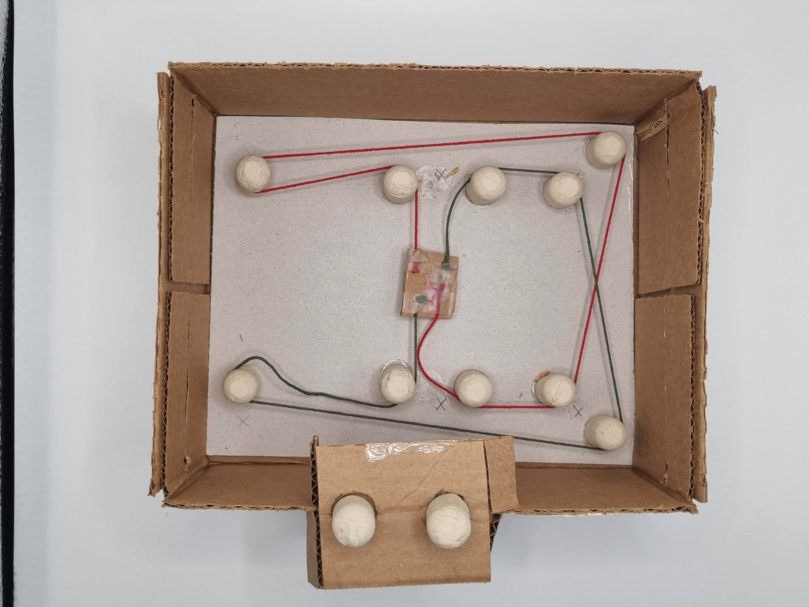
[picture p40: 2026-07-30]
Footage/Paper Prototype/Paper Prototype Assembled Top-Down.jpg

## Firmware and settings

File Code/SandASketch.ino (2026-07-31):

#include <CheapStepper.h>
#include <math.h>

CheapStepper stepperA(4, 5, 6, 7);
CheapStepper stepperB(8, 9, 10, 11);

// Hardware pin assignments
const int X_PIN = A0;
const int Y_PIN = A1;
const int SPEED_PIN = A2;
const int SW_PIN = 2;

// Joystick calibration values
int CENTER_X;
int CENTER_Y;
const int DEADZONE = 60;

// Invert joystick axes if needed
const bool INVERT_X = true;
const bool INVERT_Y = true;

// Invert motor directions if needed
const bool INVERT_MOTOR_A = false;
const bool INVERT_MOTOR_B = false;

// Stores the last step time for each motor
unsigned long lastStepA = 0;
unsigned long lastStepB = 0;

void setup() {

  Serial.begin(115200);
  pinMode(SW_PIN, INPUT_PULLUP);

  // Wait for the joystick to be released before calibration
  Serial.println("Joystick loslassen...");

  delay(1000);

  long sumX = 0;
  long sumY = 0;

  // Average multiple readings to find the joystick center
  for (int i = 0; i < 100; i++) {
    sumX += analogRead(X_PIN);
    sumY += analogRead(Y_PIN);
    delay(2);
  }

  CENTER_X = sumX / 100;
  CENTER_Y = sumY / 100;

  Serial.print("CENTER_X = ");
  Serial.println(CENTER_X);

  Serial.print("CENTER_Y = ");
  Serial.println(CENTER_Y);
}

void loop() {

  // Read and normalize the joystick position
  int rawX = analogRead(X_PIN);
  int rawY = analogRead(Y_PIN);

  // Offset from calibrated center
  float x = rawX - CENTER_X;
  float y = rawY - CENTER_Y;

  // Ignore small joystick movements
  if (abs(x) < DEADZONE) x = 0;
  if (abs(y) < DEADZONE) y = 0;

  // Normalize values to roughly -1..1
  x /= 480.0;
  y /= 480.0;

  if (fabs(x) < 0.08) x = 0;
  if (fabs(y) < 0.08) y = 0;

  // Apply optional axis inversion
  if (INVERT_X) x = -x;
  if (INVERT_Y) y = -y;

  // Convert X/Y movement into CoreXY motor movement
  float mixA = x + y;
  float mixB = x - y;

  // Keep motor values within the valid range
  mixA = constrain(mixA, -1.0, 1.0);
  mixB = constrain(mixB, -1.0, 1.0);

  // Read speed potentiometer and calculate motor speed
  float t = analogRead(SPEED_PIN) / 1023.0;

  // Cubic response curve for finer low-speed control
  // Range: 1 ms (fast) to 20 ms (slow)
  int baseInterval = 1 + (int)(19 * t * t * t);

  int intervalA = 99999;
  int intervalB = 99999;

  if (fabs(mixA) > 0.05)
    intervalA = max(1, (int)(baseInterval / fabs(mixA)));

  if (fabs(mixB) > 0.05)
    intervalB = max(1, (int)(baseInterval / fabs(mixB)));

  unsigned long now = millis();

  // Move motor A at the calculated interval
  if (now - lastStepA >= intervalA) {

    lastStepA = now;

    // Determine motor direction
    bool dir = (mixA > 0);

    if (INVERT_MOTOR_A)
      dir = !dir;

    // Execute one step on motor A
    stepperA.step(dir);
  }

  // Move motor B at the calculated interval
  if (now - lastStepB >= intervalB) {

    lastStepB = now;

    bool dir = (mixB > 0);

    if (INVERT_MOTOR_B)
      dir = !dir;

    // Execute one step on motor B
    stepperB.step(dir);
  }
}

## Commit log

2026-07-30 STL Linking
2026-07-30 STL Formatting Fix
2026-07-30 Circuit Diagram added
2026-07-30 Added Assembly Video Note on Assembly guide
2026-07-31 Added spool & spacer stls
    [SandASketch_Spacer.stl, SandASketch_Spool.stl]
2026-07-31 Updated no motor corner of coreXY
    [SandASketch_No_Motor_Corner.stl, SandASketch_No_Motor_Corner_Bar.stl]
2026-07-31 Updated Magnet Holder Top.stl
    [SandASketch_Magnet_Holder_Top.stl]
2026-07-31 Moved No Motor Corner image
2026-07-31 Added CoreXY Assembled Sides images
2026-07-31 Added pulley add img
2026-07-31 Adapted belt images
2026-07-31 Arduino Code - Added the Arduino code to the project database
2026-07-31 Specified Contributions - Iris 3D Desing und Druch -> CoreXY specified
2026-07-31 Cut img
2026-07-31 resized wiring imgs
2026-07-31 added 1 img magnet holder
